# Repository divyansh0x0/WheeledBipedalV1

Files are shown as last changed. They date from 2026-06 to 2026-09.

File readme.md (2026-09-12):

<div align="center">
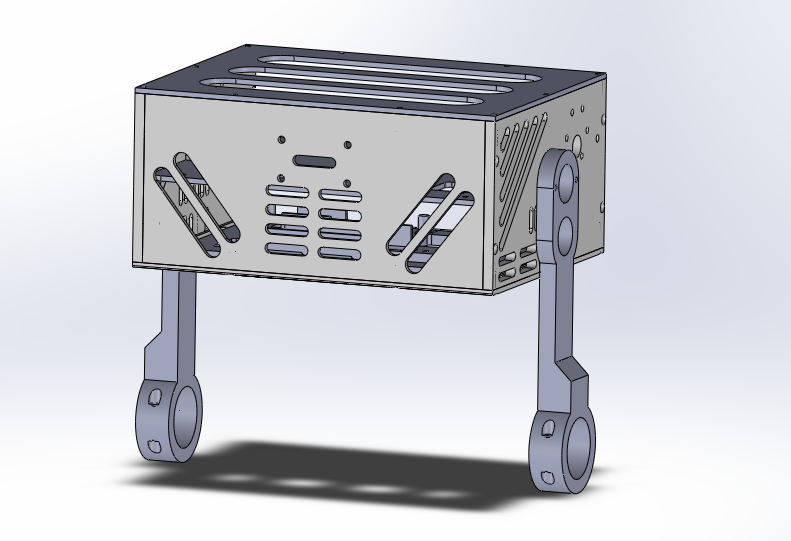
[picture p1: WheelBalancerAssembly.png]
BipedalV1 Assembly Preview
  
  <h1>BipedalV1 Firmware</h1>
  <p>Self-balancing two-wheeled robot controller based on the STM32F411CEU6.</p>
</div>

<br>

This repository contains the firmware for BipedalV1, an autonomous self-balancing platform. The system implements a rigid closed-loop PID control architecture, fusing data from a six-axis Inertial Measurement Unit (IMU) to command independent wheel actuators. It is designed for operational stability, utilizing non-blocking hardware interrupts, Direct Memory Access (DMA), and locked anti-phase motor control to ensure deterministic response times.

## System Specifications

- **Microcontroller:** STM32F411CEU6 (Cortex-M4F)
- **Memory:** 128 KB SRAM, 512 KB Flash
- **Sensors:** MPU6050 (IMU), AS5600 (Magnetic Encoder)
- **Actuation:** Dual independent DC motors via Timer-driven PWM

## Core Architecture & Working Principles

The firmware operates on a bare-metal architecture, leveraging hardware-level features of the STM32 for precise control:

- **Inertial Measurement:** Pitch and roll angles, alongside angular velocities, are sampled from the MPU6050 over an I2C bus. To maintain deterministic execution in the main loop, a hardware data-ready interrupt (EXTI) triggers DMA transactions for sensor acquisition, eliminating polling overhead.
- **Balancing Control:** A proportional-integral-derivative (PID) controller processes the IMU data to compute the required corrective motor effort. For safety, the control loop includes an automatic cutoff; power to the actuators is isolated if the chassis roll angle exceeds 30 degrees.
- **Actuator Control (Locked Anti-Phase):** The wheel motors are driven using locked anti-phase PWM generated by Timer 2. In this configuration, a 50% duty cycle holds the motor stationary, duty cycles above 50% drive the motor forward, and below 50% reverse it. This allows seamless zero-crossing speed transitions without requiring secondary direction pins.
- **Power Management:** An ADC channel continuously samples the battery voltage across a 108.52 kΩ / 33.0 kΩ voltage divider network. The logic maps the ADC readings to estimate the remaining capacity of a standard 3S LiPo pack (11.0V – 12.6V).
- **User Interface & Diagnostics:** A single tactile switch handles state inputs. A sustained one-second press initiates the MPU6050 accelerometer calibration sequence, signaled by the onboard LED. A dedicated PWM channel drives a piezo buzzer for auditory alerts.

## File Structure

```text
BipedalV1/
├── CMakeLists.txt              # CMake build configuration for ARM cross-compilation
├── linker.ld                   # GNU linker script for memory region allocation
├── readme.md                   # Project documentation
├── include/
│   ├── ActuatorManager.h       # PWM control logic for the left and right wheels
│   ├── BalancePID.h            # PID controller implementation for stabilization
│   ├── BatteryManager.h        # ADC-based battery voltage monitoring
│   ├── Buzzer.h                # PWM control logic for the buzzer
│   ├── LPC/                    # Header files for LPC components
│   └── drivers/                # Hardware abstraction layer (GPIO, I2C, MPU6050, PWM, etc.)
├── src/
│   ├── BalancePID.cpp          # PID control logic implementation
│   └── main.cpp                # Main execution loop, hardware initialization, and event handling
├── scripts/                    # Utility scripts for development and deployment
├── CAD/                        # Mechanical design files
└── startup.cpp                 # System reset handler and interrupt vector table
```

## Hardware Pin Mapping

The following hardware connections are configured in the software abstraction layer:

Motor:
- **PA1**: Left Wheel Motor pwm for DIR  (Timer 5, Channel 2) [Phased Anti-lock PWM]
- **PA2**: Right Wheel Motor pwm for DIR (Timer 5, Channel 3) [Phased Anti-lock PWM]
- **PA0**: Left Hip Motor PWM (Timer 5, Channel 1) [Sign Magnitude PWM]
- **PA3**: Right Hip Motor PWM (Timer 5, Channel 4) [Sign Magnitude PWM]
- **PA5**: Left Hip Motor Enable (Output)
- **PA6**: Left Wheel Motor Enable (Output)
- **PA7**: Right Wheel Motor Enable (Output)
- **PA8**: Right Hip Motor Enable(Output)

MPU:
- **PB9**: Multiplexer SDA (I2C2)
- **PB10**: Multiplexer SCL (I2C2)
- **PB4**: EXTI5
Multiplexer:
- **PB6**: MPU6050 SDA (I2C1)
- **PB7**: MPU6050 SCL (I2C1)

CurrentSensor:
- **PB8** - SDA3
- **PA8** - SCL3
Utility:
- **PA4**: Battery Voltage Monitoring (ADC1)
- **PB0**: Fan PWM
- **PB1**: Buzzer PWM (Timer 4, Channel 1)
- **PC13**: Onboard LED (Output, Active Low)
NRF24L01:
- **PB13**: SPI2 SCK
- **PB14**: SPI2 MISO
- **PB15**: SPI2 MOSI
- **PB12**: SPI2 Output for CSN
- **PA15**: GPIO Output for CE
- **PB5**: EXTI5

## Build & Flash Instructions

The firmware is configured via CMake and can be flashed using the onboard USB peripheral in DFU mode, or via a standard ST-Link debug probe.

### Method 1: Onboard USB (DFU)

```bash
dfu-util -a 0 -d 0483:df11 -s 0x08000000:leave -D cmake-build-debug/BipedalV1.bin
```

### Method 2: ST-Link Programmer

```bash
cmake --build cmake-build-debug/ --target BipedalV1 && st-flash write cmake-build-debug/BipedalV1.bin 0x08000000 && st-flash reset```

## Reference Documentation

- [GNU Linker Script Example](https://sourceware.org/binutils/docs/ld/Simple-Example.html)
- `ReferenceManual.pdf` — STM32F411 Reference Manual
- `programming manual.pdf` — STM32F411 Programming Manual
- `DataSheet.pdf` — STM32F411 Datasheet
- `Alternate Function Table.pdf` — GPIO Alternate Function Mappings
- [Finite State Machines (FSM) in Embedded Systems](https://www.embeddedrelated.com/showarticle/1625.php)
- [Control System (CTMS)](https://ctms.engin.umich.edu/CTMS/index.php?example=InvertedPendulum&section=ControlPID)

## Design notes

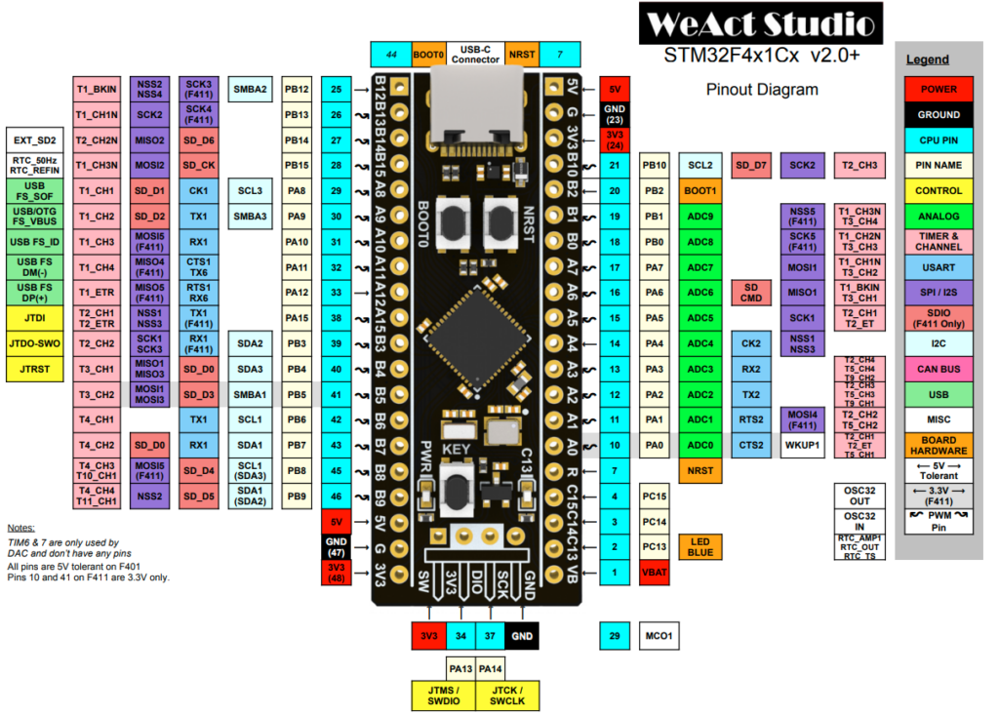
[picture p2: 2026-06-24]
pinout diagram.png

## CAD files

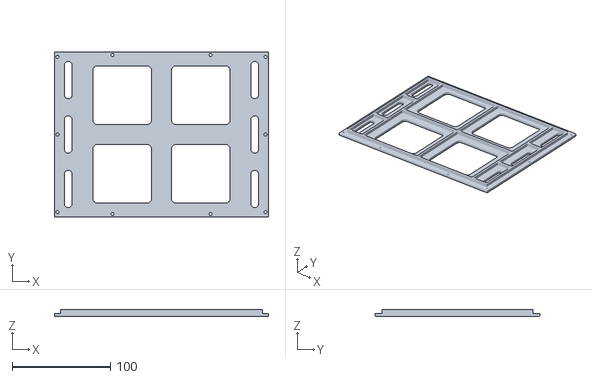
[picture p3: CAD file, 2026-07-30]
CAD/2WheelBalancer - Base-1.STL
218.0 x 168.0 x 7.00

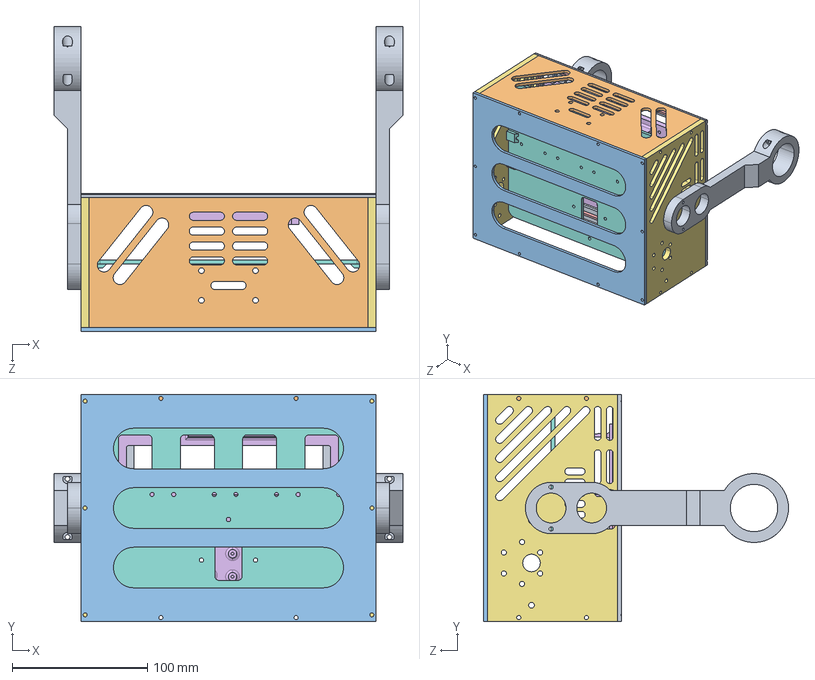
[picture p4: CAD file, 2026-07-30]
CAD/2WheelBalancer.STEP
258.0 x 168.0 x 225.5 mm
Base
BatteryHolder
Chassis x 2
CircuitBase
Shin x 2
HeadCap

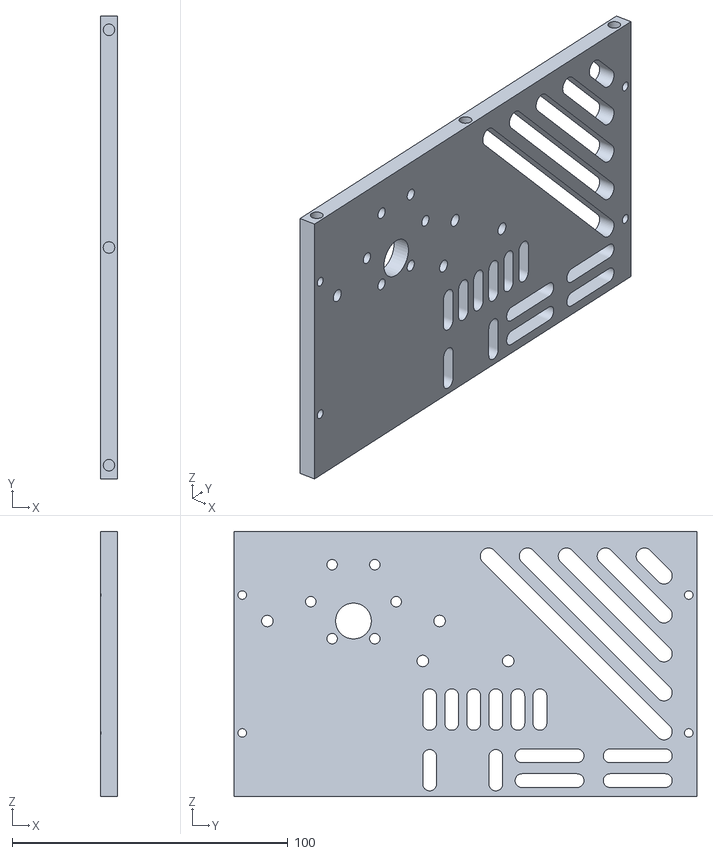
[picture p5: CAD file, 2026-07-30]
CAD/2WheelBalancer - Chassis-1.STL
6.00 x 168.0 x 96.2

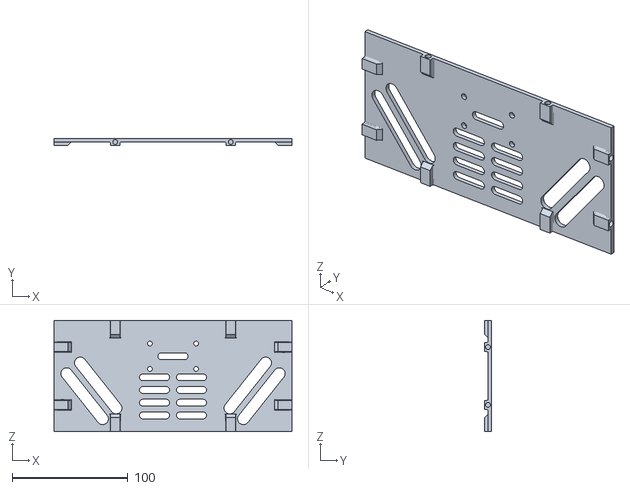
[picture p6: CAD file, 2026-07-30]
CAD/2WheelBalancer - Face-1.STL
206.0 x 6.00 x 96.2

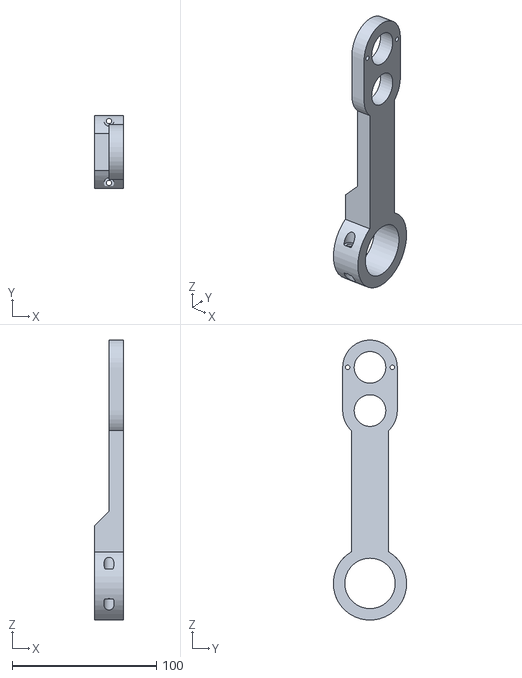
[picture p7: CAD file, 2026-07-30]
CAD/2WheelBalancer - Shin-2.STL
20.0 x 51.0 x 194.4

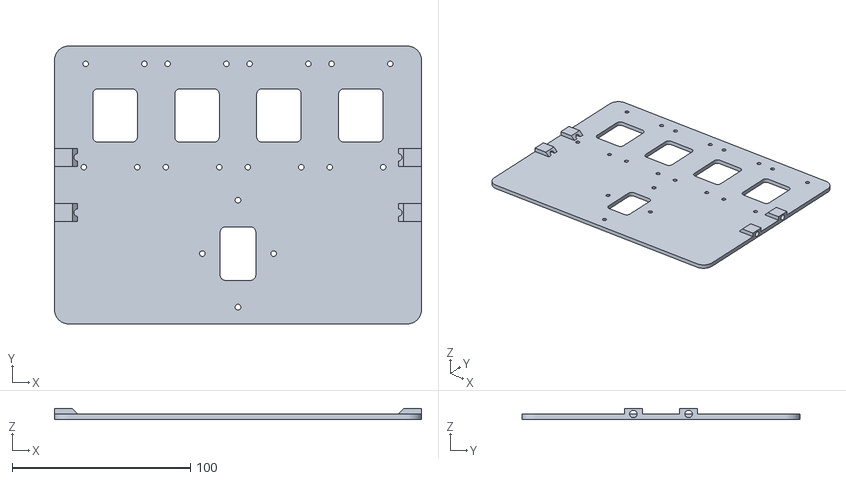
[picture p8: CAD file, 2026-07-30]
CAD/2WheelBalancer - CircuitBase-1.STL
206.0 x 156.0 x 6.00

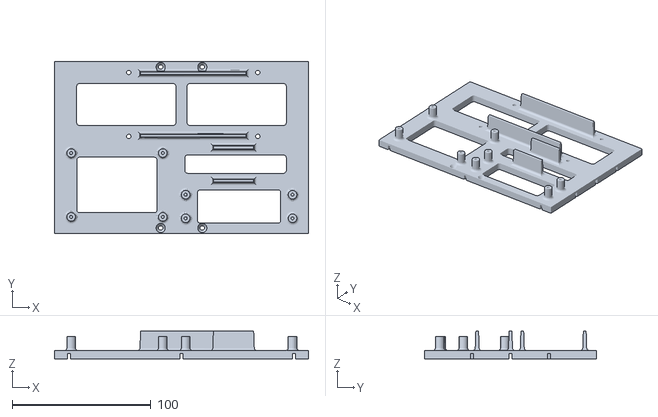
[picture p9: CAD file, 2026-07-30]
CAD/2WheelBalancer - BatteryHolder-1.STL
183.0 x 124.0 x 20.0

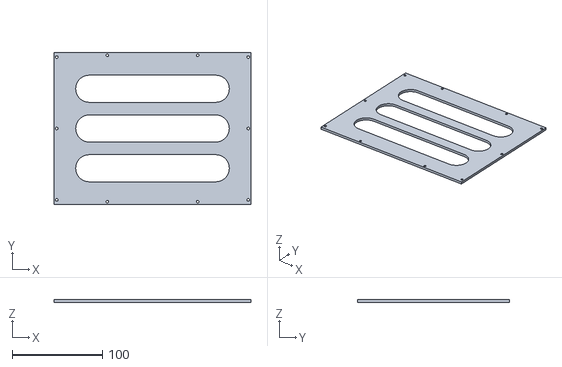
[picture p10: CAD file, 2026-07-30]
CAD/2WheelBalancer - HeadCap-1.STL
218.0 x 168.0 x 3.00

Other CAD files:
CAD/2WheelBalancer - Chassis-3.STL
CAD/2WheelBalancer - Shin-1.STL

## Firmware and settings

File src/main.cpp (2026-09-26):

#include "Context.h"
#include "ServoManager.h"
#include "drivers/Clock.h"
#include "drivers/GPIO.h"
#include "drivers/MemoryMap.h"


static inline volatile float current[2] = {};
static inline volatile float voltage[2] = {};

static inline volatile float battery_percentage;
static inline volatile float battery_voltage;
static inline volatile float roll;
static inline volatile float pitch;
static Biped::MagneticEncoder::EncoderI2CMux *mux = nullptr;;
static Biped::ServoManager *servo_manager = nullptr;;
static volatile unsigned int control_loop_rate_hz = 0;
static volatile float right_wheel_rpm = 0;
static volatile float left_wheel_rpm= 0;
static volatile float left_wheel_angle= 0;
static volatile float right_wheel_angle= 0;
[[noreturn]] int main() {
    using namespace Biped;
    using namespace F411;
    MemoryMap::RCC1->enablePeripheral(MemoryMap::APB1Peripheral::I2C1);
    MemoryMap::RCC1->enablePeripheral(MemoryMap::APB1Peripheral::I2C2);
    MemoryMap::RCC1->enablePeripheral(MemoryMap::APB1Peripheral::I2C3);
    MemoryMap::RCC1->enablePeripheral(MemoryMap::AHB1Peripheral::GPIOC);
    MemoryMap::RCC1->enablePeripheral(MemoryMap::AHB1Peripheral::GPIOB);
    MemoryMap::RCC1->enablePeripheral(MemoryMap::AHB1Peripheral::GPIOA);
    MemoryMap::RCC1->enablePeripheral(MemoryMap::AHB1Peripheral::DMA1);
    MemoryMap::RCC1->enablePeripheral(MemoryMap::APB1Peripheral::TIMER5);
    MemoryMap::RCC1->enablePeripheral(MemoryMap::APB1Peripheral::TIMER3);
    MemoryMap::RCC1->enablePeripheral(MemoryMap::APB2Peripheral::SYSCFG);
    Clock::enable();

    Pins::C13::enableOutputMode();

    Pins::B10::enableAlternateFunction<Peripherals::SCL2>();
    Pins::B9::enableAlternateFunction<Peripherals::SDA2>();

    Pins::B6::enableAlternateFunction<Peripherals::SCL1>();
    Pins::B7::enableAlternateFunction<Peripherals::SDA1>();

    Pins::B8::enableAlternateFunction<Peripherals::SDA3>();
    Pins::A8::enableAlternateFunction<Peripherals::SCL3>();

    Context::initialize();
    mux = Context::getEncoderI2CMux();
    servo_manager = Context::getServoManager();

    servo_manager->enableWheels(true);
    mux->update();
    unsigned int t1 = Clock::millis();
    unsigned int count = 0;
    while (true) {
        Context::update();
        current[0] = Context::getCurrentHipLeft();
        current[1] = Context::getCurrentHipRight();
        voltage[0] = Context::getVoltageHipLeft();
        voltage[1] = Context::getVoltageHipRight();
        battery_percentage = Context::getBatteryPercentage();
        battery_voltage = Context::getBatteryVoltage();
        roll = Context::getRoll();
        pitch = Context::getPitch();
        count++;

        if (Clock::millis() - t1 > 1000) {
            control_loop_rate_hz = count;
            Pins::C13::toggle();
            count = 0;
            t1 = Clock::millis();
        }
        right_wheel_rpm = servo_manager->getRightWheelRPM();
        left_wheel_rpm = servo_manager->getLeftWheelRPM();
        left_wheel_angle = servo_manager->getLeftWheelAngle();
        right_wheel_angle = servo_manager->getRightWheelAngle();
        servo_manager->setPWM(0.2f,0.0f);
    }
}

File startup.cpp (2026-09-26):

#include "drivers/Clock.h"
#include "drivers/Interrupt.h"
#include "drivers/MemoryMap.h"

/**
 * @brief Cortex-M4F vector table for STM32F411.
 *
 * The vector table contains:
 * - The initial stack pointer value.
 * - Exception and interrupt handler addresses.
 */
using init_func_t = void (*)();

/**
 * @brief Total length of the Interrupt Service Routine Vector (ISRV) table for F411.
 * 16 Core Exceptions + 86 Peripheral Interrupts = 102
 */
constexpr unsigned int ISRV_LENGTH = 102;

using isr_t = void (*)();

extern "C" void _estack(void);

extern "C" unsigned int
        _sidata, ///< Start address of the initialization values for the .data section in Flash.
        _sdata, ///< Start address of the .data section in SRAM.
        _edata, ///< End address of the .data section in SRAM.
        _sbss, ///< Start address of the .bss section in SRAM.
        _ebss; ///< End address of the .bss section in SRAM.

extern int main(void);

extern "C" init_func_t _sinit;
extern "C" init_func_t _einit;

/**
 * @brief Configure system clock to 96 MHz using an external 25 MHz HSE crystal.
 * STM32F411 max frequency is 100MHz. 96MHz is chosen to easily generate 48MHz for USB.
 */
static void initSystemClock() {
    // 1. Enable the External Crystal (HSE) and wait for hardware lock.
    F411::MemoryMap::RCC1->enableHSE();

    // 2. Configure Flash Latency FIRST.
    // For STM32F411 at 96MHz (3.3V VDD), 3 Wait States are required.
    F411::MemoryMap::FlashInterface->setWaitState(F411::MemoryMap::Flash::WaitStates::THREE);

    // 3. Configure and enable the PLL.
    // Target: 96 MHz SYSCLK, 48 MHz USB.
    // F4 PLL Formula: f(VCO) = f(HSE) * (N / M). f(SYSCLK) = f(VCO) / P. f(USB) = f(VCO) / Q.
    // M=25 (1MHz VCO in), N=192 (192MHz VCO out), P=2 (96MHz Core), Q=4 (48MHz USB)
    F411::MemoryMap::RCC1->enablePLL(F411::MemoryMap::RCC::PLLSource::HSE, 25, 192, 2, 4);

    // 4. Set bus prescalers BEFORE switching the system clock.
    // AHB  = 96 MHz (Prescaler = None)   -> Max 100 MHz
    // APB1 = 48 MHz (Prescaler = Half)   -> Max 50 MHz
    // APB2 = 96 MHz (Prescaler = None)   -> Max 100 MHz
    F411::MemoryMap::RCC1->setAPB1PreScaler(F411::MemoryMap::RCC::Prescaler::Half);
    F411::MemoryMap::RCC1->setAPB2PreScaler(F411::MemoryMap::RCC::Prescaler::None);
    F411::MemoryMap::RCC1->setAHBPrescaler(F411::MemoryMap::RCC::AHBPrescaler::None);

    // 5. Route the PLL to the Core.
    F411::MemoryMap::RCC1->setSystemClockSrc(F411::MemoryMap::RCC::SystemClockSource::PLL);
}

/**
 * @brief Reset handler called on processor reset.
 */
extern "C" [[noreturn]] void Reset_Handler(void) {
    // 1. Explicitly set the Vector Table Offset Register (VTOR) to Flash Base
    // Critical if MCU briefly entered the ST ROM bootloader on cold boot.
    volatile unsigned int *SCB_VTOR = (volatile unsigned int *) 0xE000ED08;
    *SCB_VTOR = 0x08000000;

    // 2. Enable Cortex-M4F Hardware Floating Point Unit (FPU)
    volatile unsigned int *SCB_CPACR = (volatile unsigned int *) 0xE000ED88;
    *SCB_CPACR |= 0xF << 20; // Set CP10 and CP11 to Full Access
    
    // Memory barriers to ensure FPU is enabled before pipeline executes any FP instruction
    // Without this, the MCU will instantly HardFault (NOCP UsageFault) on cold boot!
    asm volatile("dsb" ::: "memory");
    asm volatile("isb" ::: "memory");

    // 3. Initialize System Clocks (HSE/PLL)
    initSystemClock();

    // 4. Initialize SRAM Memory (.data and .bss)
    // Must use volatile pointers so GCC -O3 optimization doesn't delete the copy loops!
    volatile unsigned int *src = &_sidata;
    volatile unsigned int *dst = &_sdata;
    while (dst < &_edata) {
        *dst = *src;
        src++;
        dst++;
    }

    dst = &_sbss;
    while (dst < &_ebss) {
        *dst = 0;
        dst++;
    }

    // 5. Call Global C++ Constructors
    init_func_t *src_func = &_sinit;
    while (src_func < &_einit) {
        (*src_func)();
        src_func++;
    }

    // 6. Enter Main Program
    main();

    while (1) {
    }
}

static void dma1StreamInterrupt(uint8_t stream) {
    auto dma = F411::MemoryMap::DMA1;
    uint8_t bit_offset = F411::InterruptManager::TCIF_OFFSETS[stream % 4];

    // Streams 0-3 use LISR/LIFCR. Streams 4-7 use HISR/HIFCR.
    volatile F411::MemoryMap::register_t &status_reg = (stream < 4) ? dma->LISR : dma->HISR;
    volatile F411::MemoryMap::register_t &clear_reg = (stream < 4) ? dma->LIFCR : dma->HIFCR;

    // Check if the Transfer Complete Interrupt Flag is set
    if (status_reg & (1 << bit_offset)) {
        // Clear the flag to prevent an infinite interrupt loop
        clear_reg = (1 << bit_offset);

        // Execute the dynamically assigned callback
        if (F411::InterruptManager::dma_callbacks[stream] != nullptr) {
            F411::InterruptManager::dma_callbacks[stream]();
        }
    }
}

static void handleEXTI(uint8_t start_line, uint8_t end_line) {
    for (uint8_t i = start_line; i <= end_line; i++) {
        // Check if the Pending Register (PR) flag is set for this specific line
        if (F411::EXTIReg->PR & (1 << i)) {
            // CLEAR the flag by writing a 1 to it (STM32 hardware quirk: rc_w1)
            F411::EXTIReg->PR = (1 << i);

            // Execute the user's callback if it exists
            if (F411::InterruptManager::exti_callbacks[i] != nullptr) {
                F411::InterruptManager::exti_callbacks[i]();
            }
        }
    }
}

extern "C" {
// Dedicated IRQs
void EXTI0_IRQHandler() { handleEXTI(0, 0); }
void EXTI1_IRQHandler() { handleEXTI(1, 1); }
void EXTI2_IRQHandler() { handleEXTI(2, 2); }
void EXTI3_IRQHandler() { handleEXTI(3, 3); }
void EXTI4_IRQHandler() { handleEXTI(4, 4); }

// Grouped IRQs (The loop inside handleEXTI will figure out exactly which pin fired)
void EXTI9_5_IRQHandler() { handleEXTI(5, 9); }
void EXTI15_10_IRQHandler() { handleEXTI(10, 15); }

void DMA1_Stream0_IRQHandler() { dma1StreamInterrupt(0); }
void DMA1_Stream1_IRQHandler() { dma1StreamInterrupt(1); }
void DMA1_Stream2_IRQHandler() { dma1StreamInterrupt(2); }
void DMA1_Stream3_IRQHandler() { dma1StreamInterrupt(3); }
void DMA1_Stream4_IRQHandler() { dma1StreamInterrupt(4); }
void DMA1_Stream5_IRQHandler() { dma1StreamInterrupt(5); }
void DMA1_Stream6_IRQHandler() { dma1StreamInterrupt(6); }
void DMA1_Stream7_IRQHandler() { dma1StreamInterrupt(7); }
}

extern "C" void Default_Handler(void) {
    while (1) {
        // Halt execution for debugger
    }
}

extern "C" void HardFault_Handler(void) {
    while (1) {
        // Halt execution for GDB inspection
    }
}
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

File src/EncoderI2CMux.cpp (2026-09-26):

//
// Created by divyansh on 9/10/26.
//

#include "EncoderI2CMux.h"
#include "drivers/GPIO.h"

static float normalize_angle(float angle) {
    return angle > 180 ? angle - 360 : angle < -180 ? angle + 360 : angle;
}

static void encoder_read_callback(void *ctx) {
    const auto mux = reinterpret_cast<Biped::MagneticEncoder::EncoderI2CMux *>(ctx);
    Biped::MagneticEncoder::Encoder *state = mux->getCurrentEncoder();
    const uint16_t raw = static_cast<uint16_t>(state->buffer[0] << 8 | state->buffer[1]);
    const bool is_as5600 = state->type == Biped::MagneticEncoder::Encoder::EncoderType::AS5600;
    // AS5600: 12-bit angle in bits [11:0], upper 4 bits are undefined → mask
    // MT6701: 14-bit angle in bits [15:2], lower 2 bits are status  → shift
    const uint16_t angle_raw = is_as5600 ? (raw & 0x0FFF) : (raw >> 2);
    const float max_counts = is_as5600 ? 4096.0f : 16384.0f;
    const float new_angle = static_cast<float>(angle_raw) * 360.0f / max_counts;

    const unsigned int current_time = F411::Clock::micros();
    const float angle_change = normalize_angle(new_angle - state->raw_angle);
    const unsigned int dt = current_time - state->last_read_time_us;
    // RPM = (Δθ_degrees / 360) × (60 × 1e6 / Δt_us) = Δθ × 1e6 / (6 × Δt)
    const float instantaneous_rpm = (angle_change * 1e6f / 6.0f) / static_cast<float>(dt);

    // EMA low pass filter on RPM: alpha = 0.3 → heavier smoothing, 0.8 → lighter smoothing
    constexpr float alpha = 0.3f;
    state->rpm = alpha * instantaneous_rpm + (1.0f - alpha) * state->rpm;

    state->raw_angle = new_angle;
    state->normalized_angle = normalize_angle(state->raw_angle - state->reference_angle.value_or(0.0f));
    state->last_read_time_us = current_time;
    if (mux->changeChannelDMA())
        mux->updateDataDMA();
}

// static void mux_write_callback(void *ctx) {
//     const auto as5600mux = reinterpret_cast<Biped::AS5600::EncoderI2CMux *>(ctx);
//     as5600mux->updateDataDMA();
// }
static constexpr uint8_t AS5600_ADDR = 0x36;
static constexpr uint8_t MT6701_ADDR = 0x06;

enum class AS5600Registers : uint8_t {
    ZMCO = 0x0,
    ZPOS_L = 0x01,
    ZPOS_H = 0x02,
    MPOS_L = 0x03,
    MPOS_H = 0x04,
    MANG_L = 0x05,
    MANG_H = 0x06,
    CONF_H = 0x07,
    CONF_L = 0x08,
    STATUS = 0x0B,
    RAW_ANGLE_H = 0x0C, // 12-bit raw angle [11:8]
    RAW_ANGLE_L = 0x0D, // 12-bit raw angle  [7:0]
    ANGLE_H = 0x0E, // 12-bit filtered angle [11:8]
    ANGLE_L = 0x0F, // 12-bit filtered angle  [7:0]
    AGC = 0x1A,
    MAGNITUDE_H = 0x1B,
    MAGNITUDE_L = 0x1C,
};

enum class MT6701Registers : uint8_t {
    ANGLE_MSB = 0x03,
    ANGLE_LSB = 0x04,
    PUSH_BTN = 0x05,
};

namespace Biped::MagneticEncoder {
    void Encoder::readMagnetStatus() {
        if (type == EncoderType::MT6701) {
            this->status.reset();
            return;
        }

        // AS5600 read
        uint8_t temp = 0;
        if (!i2c::readRegister(AS5600_ADDR, static_cast<uint8_t>(AS5600Registers::STATUS), &temp, 1)) {
            i2c::recoverBus<F411::Pins::B6, F411::Pins::B7, F411::Peripherals::SCL1, F411::Peripherals::SDA1>();
            this->status = MagnetStatus::ReadError;
            return;
        }


        const bool md = temp & (1 << 5);
        const bool ml = temp & (1 << 4);
        const bool mh = temp & (1 << 3);

        if (!md)
            this->status = MagnetStatus::NotDetected;
        else if (ml)
            this->status = MagnetStatus::TooWeak;
        else if (mh)
            this->status = MagnetStatus::TooStrong;
        else
            this->status = MagnetStatus::OK;
    }

    void Encoder::updateAngle() {
        if (type == EncoderType::MT6701) {
            if (!i2c::readRegister(MT6701_ADDR, static_cast<uint8_t>(MT6701Registers::ANGLE_MSB), this->buffer, 2)) {
                i2c::recoverBus<F411::Pins::B6, F411::Pins::B7, F411::Peripherals::SCL1, F411::Peripherals::SDA1>();
                this->status = MagnetStatus::ReadError;
                return;
            }
        } else {
            //AS5600 read
            if (!i2c::readRegister(AS5600_ADDR, static_cast<uint8_t>(AS5600Registers::RAW_ANGLE_H), this->buffer, 2)) {
                i2c::recoverBus<F411::Pins::B6, F411::Pins::B7, F411::Peripherals::SCL1, F411::Peripherals::SDA1>();
                this->status = MagnetStatus::ReadError;
                return;
            }
        }

        const uint16_t raw = static_cast<uint16_t>(this->buffer[0] << 8 | this->buffer[1]);
        // AS5600: 12-bit angle in bits [11:0], upper 4 bits are undefined → mask
        // MT6701: 14-bit angle in bits [15:2], lower 2 bits are status  → shift
        const uint16_t angle_raw = (this->type == EncoderType::AS5600) ? (raw & 0x0FFF) : (raw >> 2);
        const float max_angle_bit = (this->type == EncoderType::AS5600) ? 4096.0f : 16384.0f;
        const float new_angle = static_cast<float>(angle_raw) * 360.0f / max_angle_bit;

        const unsigned int current_time = F411::Clock::micros();
        if (this->last_read_time_us == 0) {
            this->last_read_time_us = current_time;
            this->raw_angle = new_angle;
            return; // Can't compute RPM on first sample
        }

        const float angle_change = normalize_angle(new_angle - this->raw_angle);
        const unsigned int dt = current_time - this->last_read_time_us;
        this->rpm = (angle_change * 1e6f / 6.0f) / static_cast<float>(dt);

        this->raw_angle = new_angle;
        this->normalized_angle = normalize_angle(this->raw_angle - this->reference_angle.value_or(0.0f));
        this->last_read_time_us = current_time;
    }

    bool EncoderI2CMux::changeChannel() {
        this->active_as5600_index = (this->active_as5600_index + 1) % this->as5600_count;
        this->active_channel = this->encoder_states[this->active_as5600_index].mux_index;
        bool success = i2c::writeRegister(PCA9548A_ADDR, static_cast<uint8_t>(0b1 << this->active_channel), nullptr, 0,
                                          false);
        if (!success) {
            i2c::recoverBus<F411::Pins::B6, F411::Pins::B7, F411::Peripherals::SCL1, F411::Peripherals::SDA1>();
        }
        return success;
    }

    Encoder *EncoderI2CMux::getCurrentEncoder() {
        return &encoder_states[this->active_as5600_index];
    }

    bool EncoderI2CMux::changeChannelDMA() {
        this->active_as5600_index = (this->active_as5600_index + 1) % this->as5600_count;
        this->active_channel = this->encoder_states[this->active_as5600_index].mux_index;
        auto channel_mask = static_cast<uint8_t>(0b1 << this->active_channel);
        if (!i2c::writeRegister(PCA9548A_ADDR, channel_mask, nullptr, 0, false)) {
            i2c::recoverBus<F411::Pins::B6, F411::Pins::B7, F411::Peripherals::SCL1, F411::Peripherals::SDA1>();
        }
        // Return false when we've wrapped back to the start (full cycle done)
        return this->active_as5600_index != 0;
    }
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

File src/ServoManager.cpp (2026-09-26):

#include "ServoManager.h"

#include <numbers>

#include "BalancePID.h"
#include "Context.h"

namespace Biped {
    constexpr float MAX_ROLL_ANGLE = 45;
    static BalancePID balance_pid{0.1350f, 0.0f, 0.0040f, 0.1350f, 0.0f, 0.0040f, 0, 0};

    void ServoManager::setPWM(float left_wheel, float right_wheel) {
        const LockedAntiPhaseSpeed left_pwm{left_wheel};
        const LockedAntiPhaseSpeed right_pwm{right_wheel};

        const auto right_wheel_pwm = right_pwm.toDuty();
        m_left_wheel_pwm.setDutyCycle(left_pwm.toInvertedDuty());
        m_right_wheel_pwm.setDutyCycle(right_wheel_pwm);
    }

    void ServoManager::initialize(float wheel_radius, float hip_joint_radius, MagneticEncoder::Encoder *wheel_left,
                                  MagneticEncoder::Encoder *wheel_right, MagneticEncoder::Encoder *hip_left,
                                  MagneticEncoder::Encoder *hip_right) {
        F411::MemoryMap::RCC1->enablePeripheral(F411::MemoryMap::AHB1Peripheral::GPIOA);
        F411::MemoryMap::RCC1->enablePeripheral(F411::MemoryMap::APB1Peripheral::TIMER5);

        phased_anti_lock_pwm_enable::enableOutputMode();
        phased_anti_lock_pwm_enable::set(F411::GPIOStatus::LOW);
        upper_left_dir_pin::enableOutputMode();
        upper_left_dir_pin::set(F411::GPIOStatus::LOW);
        upper_right_dir_pin::enableOutputMode();
        upper_right_dir_pin::set(F411::GPIOStatus::LOW);

        // Set frequency FIRST so ARR is valid before channel outputs are enabled
        m_left_wheel_pwm.setFrequency(32000);
        m_right_wheel_pwm.setFrequency(32000);
        m_thigh_left_pwm.setFrequency(32000);
        m_thigh_right_pwm.setFrequency(32000);

        // Initialize phased anti-lock pwm channels to 50% duty (stopped in locked anti-phase)
        m_left_wheel_pwm.setDutyCycle(0.5f);
        m_right_wheel_pwm.setDutyCycle(0.5f);

        // Set duty of sign magnitude to zero
        m_thigh_left_pwm.setDutyCycle(0);
        m_thigh_right_pwm.setDutyCycle(0);

        // Enable timers to update generating the PWM signal internally
        m_left_wheel_pwm.enable();
        m_right_wheel_pwm.enable();
        m_thigh_left_pwm.enable();
        m_thigh_right_pwm.enable();

        // Route the fully configured timer signals to the GPIO pins
        m_pin_left_wheel_dir::enableAlternateFunction<F411::Peripherals::TIMER5>();
        m_pin_right_wheel_dir::enableAlternateFunction<F411::Peripherals::TIMER5>();
        m_pin_left_thigh_pwm::enableAlternateFunction<F411::Peripherals::TIMER5>();
        m_pin_right_thigh_pwm::enableAlternateFunction<F411::Peripherals::TIMER5>();

        this->servos.hip_left = hip_left;
        this->servos.hip_right = hip_right;
        this->servos.wheel_left = wheel_left;
        this->servos.wheel_right = wheel_right;
        this->servos.wheel_right = wheel_right;

        constexpr float Kp = 0.012
        ;
        constexpr float Ki = 0.008;

        l_wheel_pid_config.kp = Kp;
        l_wheel_pid_config.ki = Ki;
        l_wheel_pid_config.integral_max = 1.0f/Ki;
        l_wheel_pid_config.output_max = 1.0f;

        r_wheel_pid_config.kp = Kp;
        r_wheel_pid_config.ki = Ki;
        r_wheel_pid_config.integral_max = 1.0f/Ki;
        r_wheel_pid_config.output_max = 1.0f;

        this->l_wheel_pi_controller.initialize(&l_wheel_pid_config, nullptr);
        this->r_wheel_pi_controller.initialize(&r_wheel_pid_config, nullptr);
        phased_anti_lock_pwm_enable::set(F411::LOW);
    }

    void ServoManager::enableWheels(bool enable) {
        phased_anti_lock_pwm_enable::set(enable ? F411::HIGH : F411::LOW);
    }

    void ServoManager::rotateHip(const float speed_left, const float speed_right) {
        if (speed_left < 0) {
            upper_left_dir_pin::set(F411::LOW);
        } else {
            upper_left_dir_pin::set(F411::HIGH);
        }
        if (speed_right < 0) {
            upper_right_dir_pin::set(F411::LOW);
        } else {
            upper_right_dir_pin::set(F411::HIGH);
        }

        m_thigh_left_pwm.setDutyCycle(speed_left < 0 ? -speed_left : speed_left);
        m_thigh_right_pwm.setDutyCycle(speed_right < 0 ? -speed_right : speed_right);
    }

    void ServoManager::setLeftWheelRPM(float rpm) {
        l_wheel_pid_config.target = rpm;
    }

    void ServoManager::setRightWheelRPM(float rpm) {
        r_wheel_pid_config.target = -rpm;
    }

    void ServoManager::setWheelRPM(const float rpm_left, const float rpm_right) {
        setLeftWheelRPM(rpm_left);
        setRightWheelRPM(rpm_right);
    }


    void ServoManager::update() {
        const float left_wheel_pid_output = l_wheel_pi_controller.getValue(servos.wheel_left->rpm, 0);
        const float right_wheel_pid_output = r_wheel_pi_controller.getValue(servos.wheel_right->rpm, 0);

        setPWM(left_wheel_pid_output, right_wheel_pid_output);
    }
}

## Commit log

2026-06-29 feat: add I2C driver
2026-06-30 feat: add clock class for millis(), micros() and clock speed functions for different buses
2026-07-02 feat: add ADC driver
2026-07-03 feat: add pwm class
2026-07-08 feat: add interrupt manager for EXTI and DMA
2026-07-09 fix: MPU6050 driver working correctly
    [I2C.h, MPU6050.h, MemoryMap.h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]
2026-07-15 feat: add as5600 mux and motor controller
2026-07-17 feat: add speed correction for phase anti locked anti-phase speed.
    [PWM.h, main.cpp]
2026-07-17 feat: add buzzer class
    [main.cpp]
2026-07-17 feat: add battery manager
2026-07-23 feat: Add Balance PID loop
2026-07-25 feat(scripts): add motor constraint
2026-07-27 feat: add PID balance loop to the robot
2026-07-29 feat: mpu6050 complimentary filter now handles variable time which improves PID performance
2026-07-29 feat: correct the PID parameters and target angle of robot
    [main.cpp]
2026-07-29 feat(stm32): fix startup delay of mpu6050 causing the interrupt to never fire by adding a startup wait time
    [main.cpp]
2026-07-29 feat: fix buzzer and battery manager
    [main.cpp]
2026-07-30 chore: add cad files
    [2WheelBalancer - BatteryHolder-1.STL, 2WheelBalancer - Chassis-1.STL, 2WheelBalancer - Chassis-3.STL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]
2026-07-30 chore: add cad assembly files
    [2WheelBalancer Assembly.STL, 2WheelBalancer.STEP]
2026-07-30 feat: add assembly files
    [2WheelBalancer - Base-1.STL]
2026-07-30 feat: update readme to reflex the current source code
2026-08-26 feat: switch to timer10 for millis and micros clock functions
2026-08-26 feat: update motor pins and actuator manager for thighs and wheels
2026-08-26 fix: startup script failing due to Clock::enable() inside initSystemClock
    [main.cpp, startup.cpp]
2026-08-26 fix: floating point operations now work
    [startup.cpp]
2026-08-26 fix: buzzer class now works correctly
    [main.cpp]
2026-08-27 feat: add state machine for buzzer and fan control
    [main.cpp]
2026-09-05 feat: add ina219 driver
2026-09-05 feat: improve structure of ina219 driver to ensure extension is easy
2026-09-10 fix: improve variable names
    [ActuatorManager.cpp, Context.cpp, main.cpp]
2026-09-10 chore: rename namespace of AS5600MUX from STM32F411 to Biped
2026-09-10 fix I2C using last output state written to GPIO for SDA pin state.
    [I2C.h]
2026-09-10 feat: read as5600 raw angle without DMA
2026-09-10 feat: fix a bug in micros function making it dma interrupt safe
    [main.cpp]
2026-09-12 feat: add normalization and homing of angle read by as5600 and
2026-09-12 feat: add general purpose pid control for wheels
2026-09-12 feat: add PI controller for velocity control of wheels
2026-09-12 feat: improve stability of velocity controller of servo
    [Context.cpp, ServoManager.cpp, main.cpp]
2026-09-26 feat: make encoder mux handle mt6701 magnetic encoder
2026-09-26 chore: use separate namespace for stm32 drivers and biped drivers
2026-09-26 feat: fix encoder mux bugs
    [Context.cpp, EncoderI2CMux.cpp, PWM.h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]
2026-09-26 feat: add rpm calculation to encoder mux
2026-10-26 change sample rate of encoders
2026-10-27 chore: update index of right wheel encoder
2026-10-27 feat: add encoder oversampling of wheel angle and EMA filter to rpm
2026-10-27 feat: add PI velocity controller and update EncoderMux to allow CCW/CW to be positive on demand
2026-10-27 feat: update Kp and Kd of PI velocity controller
2026-10-28 feat: implement cascaded balance pid
2026-10-28 tune balancer pid controller
2026-10-31 add STL files and code cleanup
